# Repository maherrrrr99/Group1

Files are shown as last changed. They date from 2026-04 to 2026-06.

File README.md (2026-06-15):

# Pick-and-Place Robot Workflow

This project uses a laptop for YOLO detection, a Raspberry Pi as the camera and command bridge, and an Arduino for the arm, suction pump, and platform motors.

The suction pump is controlled through a relay on Arduino pin `D10`. The command names are unchanged: `SUCTION_CUP_ON` energizes the relay and `SUCTION_CUP_OFF` releases it.

## Expected Network Setup

- Raspberry Pi IP: `192.168.1.62`
- Pi camera stream: `http://192.168.1.62:8080/?action=stream`
- Pi receiver TCP port: `5000`
- Pi website command bridge: `http://192.168.1.62:5001`
- Laptop sender message format: `ball,x,y,distance`
- Arduino serial: `/dev/ttyACM0` or `/dev/ttyUSB0`, baud `9600`

## Start Camera Stream On Raspberry Pi

From the `mjpg_streamer` folder on the Raspberry Pi:

```bash
./mjpg_streamer -i "./input_uvc.so -d /dev/video0 -r 240x180 -f 7 -q 25" -o "./output_http.so -w ./www -p 8080"
```

Verify from the laptop:

```text
http://192.168.1.62:8080/?action=stream
```

## Start Raspberry Pi Receiver

Copy or keep `pi_receiver.py` on the Raspberry Pi, then run:

```bash
python3 -m pip install pyserial
python3 pi_receiver.py
```

The receiver listens on `0.0.0.0:5000` for laptop YOLO data and `0.0.0.0:5001` for website manual commands. It auto-detects `/dev/ttyACM0` or `/dev/ttyUSB0`, and sends `PLATFORM_STOP` whenever data is lost, the laptop disconnects, or the receiver starts.

Verify the website command bridge from the laptop:

```powershell
Invoke-WebRequest http://192.168.1.62:5001/status
```

Object tracking is enabled in `pi_receiver.py` with these safe defaults:

- Platform speed command on startup: `PLATFORM_BOTH_MOTORS_SPEED:SLOW`
- Centering dead zone: `20` pixels around frame center X `160`
- Target ball distance: `25 cm`
- Distance dead zone: `4 cm`
- Tracking command order: turn left/right first, then move forward/backward only after the ball is centered

To make tracking more cautious, increase `TARGET_DISTANCE_CM`, increase `DISTANCE_DEAD_ZONE_CM`, or set `AUTONOMOUS_TRACKING_ENABLED = False` in `pi_receiver.py`.

Calibrated physical home:

- Elbow command `55` = physical elbow `90` degrees
- Wrist command `0` = physical wrist `0` degrees
- Gripper command `90` = home gripper angle

Calibrated elbow endpoints for website control:

- Physical elbow `0` degrees sends Arduino command `10`
- Physical elbow `90` degrees sends Arduino command `55`
- Physical elbow `180` degrees sends Arduino command `115`

The website elbow slider shows physical degrees. It converts those physical degrees to the calibrated Arduino command before sending `ELBOW_JOINT:<angle>`.

Calibrated wrist endpoints for website control:

- Physical wrist `0` degrees sends Arduino command `0`
- Physical wrist `80` degrees sends Arduino command `110`

The wrist is capped at physical `80` degrees because Arduino command `110` is the measured safe maximum.

Arm pickup is guarded by `PICKUP_SEQUENCE_ENABLED = False` until calibration is complete. Use `arm_calibration.py` on the Raspberry Pi to find safe values first, then copy those values into:

- `PICKUP_TRIGGER_DISTANCE_CM`
- `PICKUP_ELBOW_ANGLE`
- `PICKUP_WRIST_ANGLE`
- `PICKUP_GRIPPER_ANGLE`
- `PICKUP_USE_SUCTION`

## Calibrate Arm Angles On Raspberry Pi

Stop autonomous tracking first so no platform commands are active:

```powershell
Get-Process python,py | Stop-Process -Force
```

Then on the Raspberry Pi:

```bash
pkill -f pi_receiver.py
python3 ~/arm_calibration.py
```

Calibration controls:

```text
e / E : elbow -5 / +5 degrees
w / W : wrist -5 / +5 degrees
g / G : gripper -5 / +5 degrees
s     : suction cup on
x     : suction cup off
h     : home
p     : platform stop
?     : print current values
q     : quit
```

Record the elbow, wrist, and gripper values that place the tool safely at the egg.

## Live Feed Delay

The website preview can lag because browser MJPEG display buffers frames. Use the laptop YOLO sender log and Pi receiver log for control timing. For less delay, keep the stream low resolution and refresh/restart `mjpg_streamer` if the browser preview falls behind.

## Run Laptop YOLO Sender

From this project folder on the laptop:

```bash
python -m pip install ultralytics opencv-python
python laptop_yolo_sender.py
```

The script uses:

```text
train27-20260608T072150Z-3-001/train27/weights/best.pt
```

It sends only the most confident `ball` detection every `0.3` seconds.

For autonomous object tracking, start the Raspberry Pi receiver first, then run this laptop sender. The receiver will stop the platform automatically if ball data stops for more than `1` second.

## Run Website

From the website folder:

```bash
cd "pick and place website/pick and place website/2026-05-19/i-am-working-on-a-mechatronics/arm-controller"
npm install
npm run dev
```

Open:

```text
http://localhost:5173
```

Use Chrome or Edge for Web Serial.

### HC-05 Bluetooth manual control

The Arduino sketch uses `SoftwareSerial bluetooth(2, 3)` at `9600` baud:

```text
HC-05 TXD -> Arduino D2  (Arduino software RX)
HC-05 RXD -> Arduino D3  (Arduino software TX, use a voltage divider)
HC-05 VCC -> Arduino 5V
HC-05 GND -> Arduino GND
```

Pair the HC-05 in Windows first, then open the website, choose `Bluetooth`, click connect, and select the HC-05/SPP COM port. The website sends the same command names used by USB serial, such as `HOME`, `PLATFORM_STOP`, `ELBOW_JOINT:<angle>`, and `SUCTION_CUP_ON`.

To control the Arduino through the Raspberry Pi instead of HC-05/USB, choose `Autonomous Network`; the website sends commands to `http://192.168.1.62:5001/command`.

Keep the existing Arduino command names, including `PLATFORM_LEFT`, `PLATFORM_RIGHT`, `PLATFORM_STOP`, `HOME`, `EMERGENCY_STOP`, `RESET_EMERGENCY`, `SUCTION_CUP_ON`, and `SUCTION_CUP_OFF`.

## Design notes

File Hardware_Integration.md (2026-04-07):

### ● Hardware Integration
The robotic system is built around a combination of a Raspberry Pi and an Arduino, which together enable both high-level processing and low-level control. The Raspberry Pi is responsible for vision processing, object detection, and decision-making using camera input, while the Arduino handles real-time control of the actuators by generating PWM signals for the motors. Communication between the two controllers is achieved through serial communication (USB or UART), allowing coordinated system operation.

The actuation system is based on multiple servo motors selected according to torque and functional requirements. MG995 servo motors (270° rotation) are used for standard joints, providing sufficient torque for base and intermediate movements. For heavier joints such as the elbow, a 20 kg·cm high-torque servo motor (270° rotation) is used to ensure stability and lifting capability. The gripper mechanism is controlled using an SG90 micro servo (180° rotation), which offers lightweight and precise motion for opening and closing actions. All motors are controlled using PWM signals from the Arduino, and no external encoders are required since the servos include built-in potentiometers, enabling closed-loop position control.
<div align="center">

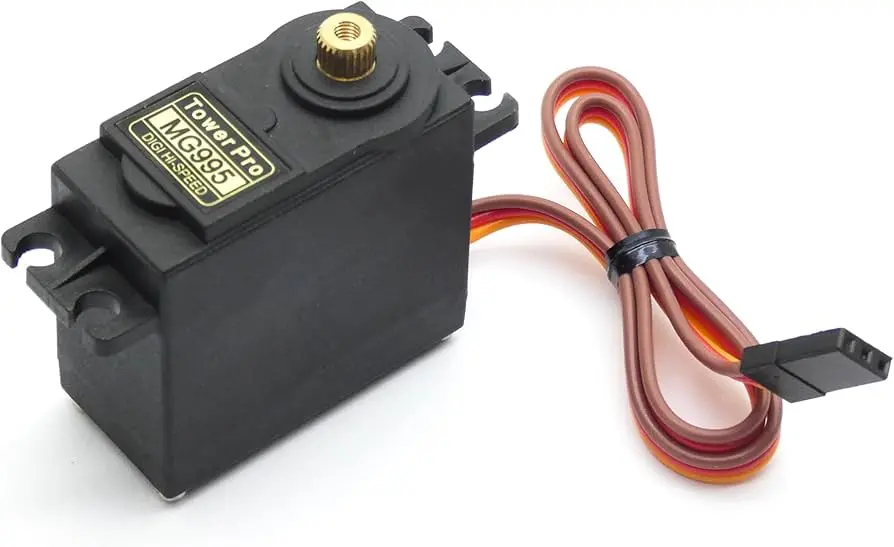
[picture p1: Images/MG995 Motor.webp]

&nbsp;&nbsp;&nbsp;&nbsp;&nbsp;&nbsp;
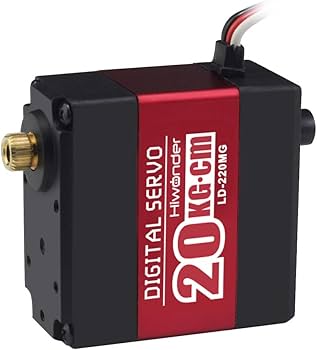
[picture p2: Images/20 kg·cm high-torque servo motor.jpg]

&nbsp;&nbsp;&nbsp;&nbsp;&nbsp;&nbsp;
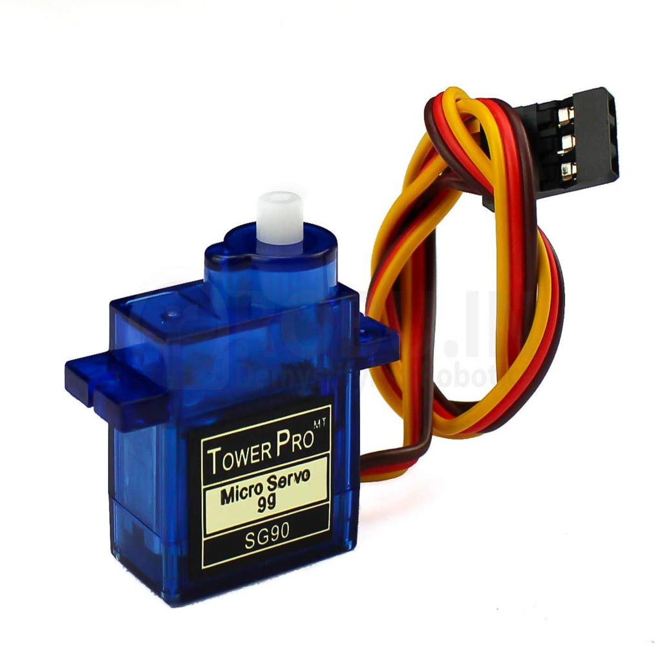
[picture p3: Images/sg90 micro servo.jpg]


<br>

<em>Figure 1: MG995 Servo Motor (left), 20 kg·cm High-Torque Servo (center), and SG90 Micro Servo (right)</em>

</div>

For sensing and object detection, the system integrates a camera connected to the Raspberry Pi. The current design considers either the Raspberry Pi Camera Module, which offers seamless integration and low latency, or a smartphone camera as an alternative for higher image quality. The camera provides real-time visual feedback, which is processed using computer vision and AI techniques to identify and locate objects for pick-and-place operations.
<p align="center">
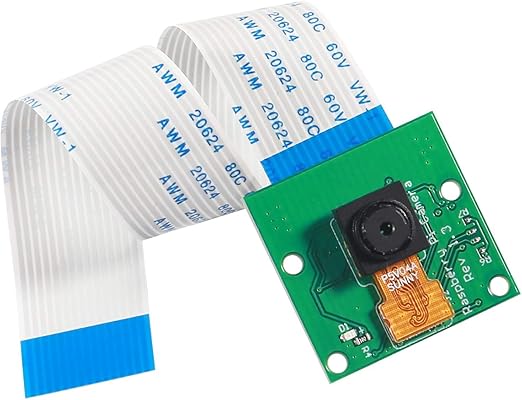
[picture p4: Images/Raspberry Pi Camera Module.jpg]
  
</p>
<p align="center"><em>Figure 2: Raspberry Pi Camera Module</em></p>

In terms of hardware layout and wiring, the servo motors are connected to the Arduino’s PWM pins and powered using an external power supply to ensure stable operation and prevent overloading the control board. The Raspberry Pi interfaces directly with the camera and communicates with the Arduino to send control commands based on processed visual data. This architecture allows efficient integration of mechanical, electronic, and intelligent subsystems, resulting in a flexible and scalable mechatronic system.

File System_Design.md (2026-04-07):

## ○ System Design

### ● Concept Development
The concept development process was iterative and systematic, building on existing literature and proven industrial designs rather than trying to reinvent the wheel. The goal was to adapt known pick-and-place mechanisms into a compact, efficient system that meets our specific needs. Throughout the design process, we focused on keeping the structure simple, durable, and practical, while also making sure it could be manufactured easily and affordably in a lab setting using tools like laser cutting and 3D printing. Another key consideration was compatibility with widely available, off-the-shelf components such as MG995 servo motors and Arduino-based control systems, which helped keep costs low and integration straightforward. Design decisions were guided by requirements like strength, reliability, and repeatability, while working within constraints such as limited resources and fabrication methods. The end result is a compact, robust design that can withstand repeated use without compromising performance.

### ● CAD Modeling
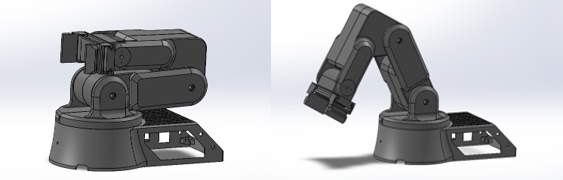
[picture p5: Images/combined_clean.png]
CAD Rendering


Figure 1: CAD Model in home and extended position.
- [CAD (SolidWorks) ](CAD_SolidWorks.zip)
- [STEP File](assembly.STEP)

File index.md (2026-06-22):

# Smart Pick-and-Place Robot
### MEC483 — Mechatronic System Design · Spring 2025–2026
#### College of Engineering · Instructor: Dr. Claudio Vignola

<p align="center">
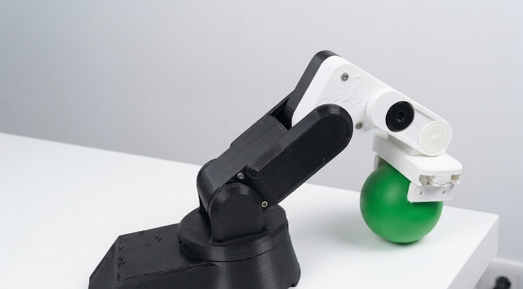
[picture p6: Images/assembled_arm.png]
  
</p>

---

## Team Members

- [Maher Abo Abed](https://maherrrrr99.github.io/maherrrrr99/)
- [Sabeeha Zainab Hasham](https://sabeehahasham.github.io/)
- [Basel Feras Ghunaim](https://basel-ghunaim.github.io/)
- [Ahmed Nasser Alshehhi](https://ahmed1090822.github.io/Ahmed109.github.io/)

---

## Problem Statement

Modern manufacturing and automation systems demand fast, accurate, and reliable object handling. Manual pick-and-place operations are slow, prone to human error, and unsuitable for repetitive, high-precision tasks. Traditional robotic systems are typically designed to work with objects in fixed locations and cannot adapt to changing environments.

To tackle these challenges, this project builds a **Smart Pick-and-Place Robotic System** with integrated computer vision. The system automatically identifies objects in a workspace, determines their positions, and commands a robotic arm to pick and place them — entirely without human intervention. It combines sensing, image processing, embedded control, and mechanical actuation into a smart, efficient automation solution.

### Impact

The system demonstrates the application of mechatronic engineering principles through the tight integration of mechanical, electrical, control, and computer engineering subsystems. By embedding computer vision directly into the robotic arm pipeline, the system improves detection precision and reduces reliance on manual handling. The platform also serves as a foundation for future developments in advanced object recognition and fully autonomous industrial robotics.

### Design Criteria

| # | Criterion | Goal |
|---|---|---|
| CR-1 | Object Detection Accuracy | Reliable identification of eggs, nuts, bolts, balls, and compasses |
| CR-2 | Pick-and-Place Success Rate | Consistent end-to-end cycle completion |
| CR-3 | Positioning Accuracy | Precise placement with minimal offset |
| CR-4 | Response Time | Low-latency vision-to-motion pipeline |
| CR-5 | Payload Capacity | Handle objects up to 250 g |
| CR-6 | Repeatability | Consistent performance across multiple cycles |
| CR-7 | Workspace Coverage | Full reach over the 30 cm platform footprint |

---

## The Robot

The final system is a **3-DOF robotic arm** mounted on a **differential-drive mobile platform**. The arm integrates a hybrid end-effector combining a rack-and-pinion mechanical gripper and a vacuum suction cup, enabling it to handle a wide variety of object shapes and textures. A Logitech C270 webcam feeds a live stream to a laptop running YOLOv8; detections are relayed over TCP to a Raspberry Pi 4 which sends joint commands to an Arduino Uno controlling the servo motors and suction pump.

<p align="center">
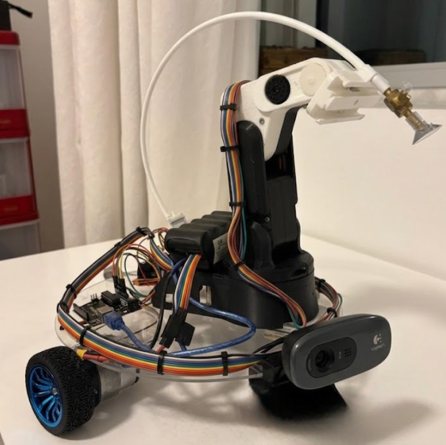
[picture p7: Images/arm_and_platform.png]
  
</p>
<p align="center"><em>Fig 1: Fully assembled arm mounted on the 30 cm acrylic laser-cut platform</em></p>

<p align="center">
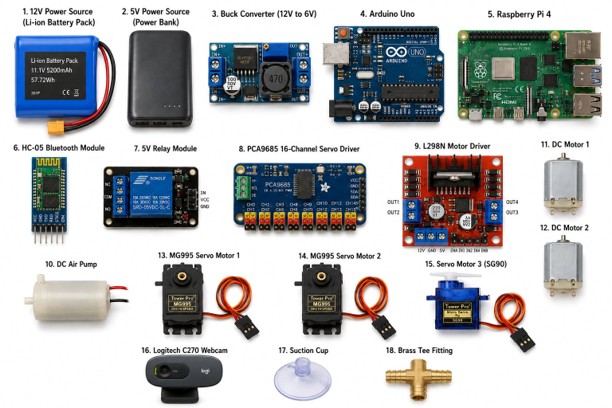
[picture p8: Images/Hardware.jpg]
  
</p>
<p align="center"><em>Fig 2: Complete hardware setup — electronics, arm, platform, and camera</em></p>

### Workspace Envelope

| Measurement | Value |
|---|---|
| Platform diameter (home footprint) | 30 cm |
| Extended arm reach beyond platform edge | ~16.5 cm |
| Maximum reach to lowest point (incl. suction cup) | **~22 cm** |
| Maximum horizontal reach (height unconstrained) | **~26 cm** |
| IK solver validated range — X | 0.05 – 0.20 m |
| IK solver validated range — Y | −0.10 – 0.10 m |
| IK solver validated range — Z | 0.02 – 0.07 m |

---

## CAD Design

The robot was modelled entirely in SolidWorks. All structural components — base, elbow, wrist, end-effector — were designed for 3D printing in PLA on a Raise3D E2 printer, with servo pockets and horn-mounting features printed accurately at each joint. The platform chassis was laser-cut from acrylic for flatness and rigidity, ensuring accurate motor alignment for differential drive.

<p align="center">
  
</p>
<p align="center"><em>Fig 3: CAD model — home position (left) and fully extended position (right)</em></p>

<p align="center">
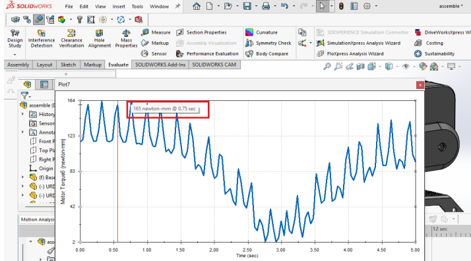
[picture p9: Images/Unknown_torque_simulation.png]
  
</p>
<p align="center"><em>Fig 4: SolidWorks Motion Study — torque simulation with 250 g payload confirms motor selection</em></p>

The torque simulation confirmed that the MG995 servos (rated ~11 kg·cm at 6 V) comfortably cover the worst-case joint loads when the arm is fully extended with a 250 g object, validating the actuator selection before any physical parts were built.

- [SolidWorks CAD Files](CAD_SolidWorks.zip)
- [STEP Assembly File](assembly.STEP)
- [STL Files for 3D Printing](STL.zip)

---

## Gripper Design

The end-effector uses a **rack-and-pinion mechanical gripper** combined with a **vacuum suction cup**, both 3D-printed in PLA. The pinion is attached directly to the output shaft of an SG90 servo, driving two symmetric linear racks that open and close the jaws. The suction cup is mounted coaxially on top of the gripper casing, connected to a 6 V DC air pump via a relay on Arduino pin D10 — allowing either gripping mode to be used independently based on the object type.

<p align="center">
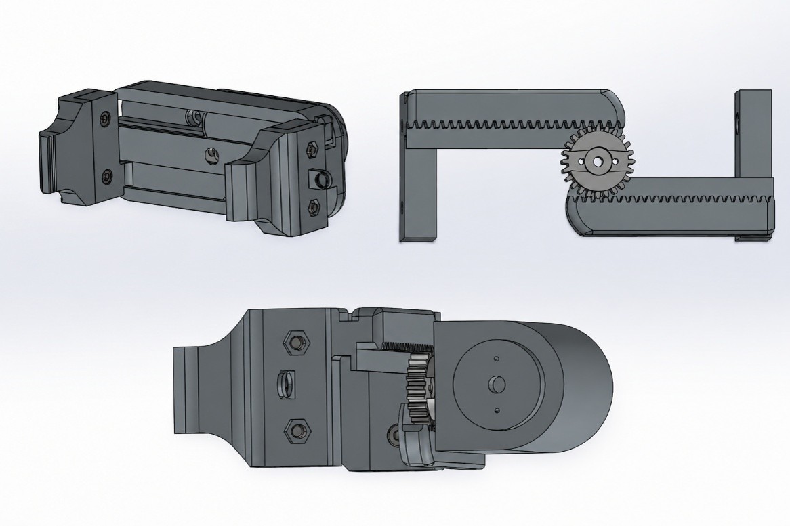
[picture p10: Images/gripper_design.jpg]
  
</p>
<p align="center"><em>Fig 5: 3D-printed hybrid gripper — rack-and-pinion jaws (bottom) and suction cup (top)</em></p>

| Mode | Best For | Control |
|---|---|---|
| Mechanical gripper | Nuts, bolts, rigid objects | SG90 servo via PCA9685 |
| Vacuum suction | Eggs, flat surfaces, smooth objects | DC pump via relay on Arduino D10 |

---

## Kinematics

### Forward Kinematics

The kinematic chain (`base_link → elbow_link → wrist_link → arm_link → end_link`) was modelled in URDF, exported from SolidWorks STL meshes. The URDF was validated in `robot_state_publisher` and visualised in RViz, confirming correct link orientation, joint hierarchy, and workspace geometry. Joint sliders were used to command each joint independently and verify that the forward kinematics matched the physical arm's motion.

<p align="center">
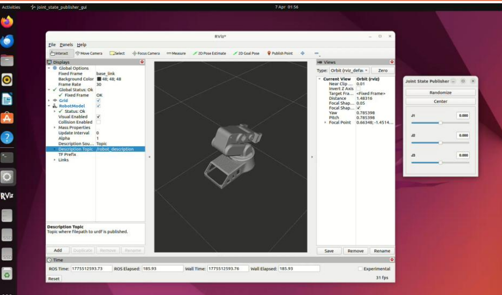
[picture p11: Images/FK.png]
  
</p>
<p align="center"><em>Fig 6: Forward kinematics visualisation in RViz — joint slider control</em></p>

### Inverse Kinematics

An IK pipeline was built with **ROS 2 Humble** and **MoveIt 2**, using the KDL solver configured for **position-only IK** (`position_only_ik: true`). This is appropriate for pick-and-place: the solver computes joint angles for a given (X, Y, Z) target without constraining end-effector orientation. A `workspace_scan.cpp` node swept a of 40 Cartesian test points and confirmed **100% reachability** across the full operating workspace.

<p align="center">
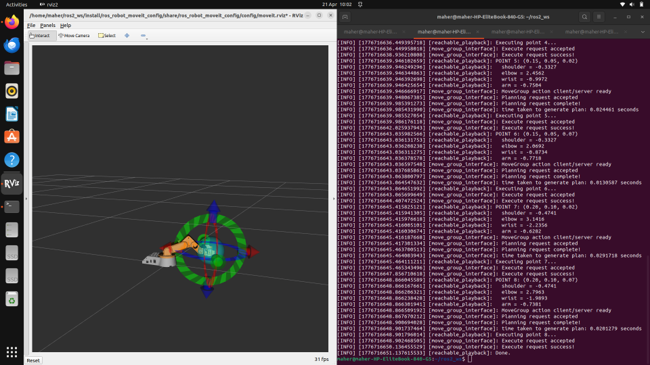
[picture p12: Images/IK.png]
  
</p>
<p align="center"><em>Fig 7: Inverse kinematics — workspace scan in RViz confirming 100% reachability over 40 test points</em></p>

#### Validated Reachable Points (sample)

| X (m) | Y (m) | Z (m) | Result |
|---|---|---|---|
| 0.05 | 0.00 | 0.02 | ✅ Reachable |
| 0.10 | 0.05 | 0.07 | ✅ Reachable |
| 0.20 | 0.10 | 0.07 | ✅ Reachable |
| 0.15 | −0.05 | 0.04 | ✅ Reachable |
| 0.08 | −0.10 | 0.05 | ✅ Reachable |

<p align="center">
  
</p>
<p align="center"><em>Fig 8: URDF robot simulation — motion planning in RViz</em></p>

### ROS Package

The full ROS 2 package is included in the [`ROS/`](ROS/) directory:

| File / Folder | Description |
|---|---|
| [`ROS/urdf/ros.urdf`](ROS/urdf/ros.urdf) | URDF kinematic model of the arm |
| [`ROS/meshes/`](ROS/meshes/) | STL meshes for each link (base, elbow, wrist, arm, end effector) |
| [`ROS/launch/display.launch`](ROS/launch/display.launch) | RViz visualisation launch file |
| [`ROS/launch/gazebo.launch`](ROS/launch/gazebo.launch) | Gazebo simulation launch file |
| [`ROS/config/joint_names_ros.yaml`](ROS/config/joint_names_ros.yaml) | Joint name configuration |
| [`ROS/package.xml`](ROS/package.xml) | ROS package manifest |
| [`ROS/CMakeLists.txt`](ROS/CMakeLists.txt) | Package build configuration |

```bash
# Visualise the arm in RViz
ros2 launch ros display.launch

# Run in Gazebo simulation
ros2 launch ros gazebo.launch
```

- [URDF Model File (legacy)](Files/urdf.urdf)

---

## Electrical System

The electrical architecture is split across three voltage rails to keep logic and power isolated:

- **12 V** — main Li-ion battery pack (12 V, 3000 mAh, 36 Wh)
- **6 V** — buck converter output for all actuators (servos, DC motors, air pump)
- **5 V** — regulated supply for Arduino, Raspberry Pi, Bluetooth module, and all signal lines

All grounds are tied to a single common bus to prevent electrical noise from high-current motor and servo wiring from interfering with signal lines.

<p align="center">
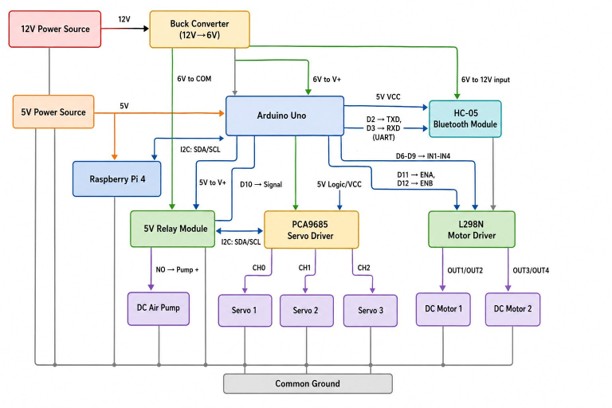
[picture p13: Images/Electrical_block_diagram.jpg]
  
</p>
<p align="center"><em>Fig 9: Final electrical block diagram</em></p>

<p align="center">
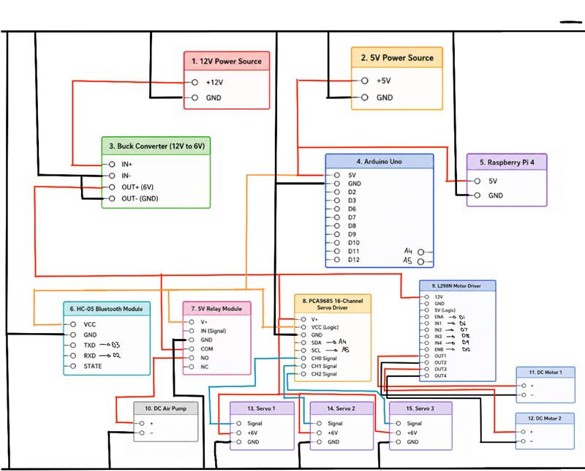
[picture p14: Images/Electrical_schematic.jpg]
  
</p>
<p align="center"><em>Fig 10: Electrical schematic — red: 12–6 V power, black: ground, blue: servo signals, orange: 5 V VCC</em></p>

### Power Budget Summary

| Subsystem | Voltage | Peak Current | Peak Power |
|---|---|---|---|
| MG995 Servo × 2 (Wrist + Elbow) | 6 V | 2.0 A each | 12.0 W each |
| SG90 Servo (Gripper) | 6 V | 650 mA | 3.9 W |
| DC Motor × 2 (Platform) | 6 V | 1.2 A each | 7.2 W each |
| DC Air Pump | 6 V | 400 mA | 2.4 W |
| Raspberry Pi 4 | 5 V | 1.2 A | 6.0 W |
| Arduino Uno | 5 V | 80 mA | 0.4 W |
| **6 V Rail Total (peak)** | 6 V | **7.45 A** | **44.7 W** |
| **Estimated runtime (normal use)** | — | — | **~4 hours** |

### Component Selection

All major components were chosen using weighted decision matrices (scored 1–5). Key results:

| Component | Selected | Score | Runner-up |
|---|---|---|---|
| Microcontroller | Arduino UNO | 4.20 | ESP32 (3.70) |
| Camera | Logitech C270 | 4.85 | InnoMaker USB (2.75) |
| Mini-computer | Raspberry Pi 4 | 4.60 | NVIDIA Jetson Nano (2.60) |
| Arm actuator | MG995 / SG90 Servo | 4.30 | DC Motor + Gearbox (2.80) |

<div align="center">
  
  &nbsp;&nbsp;&nbsp;
  
  &nbsp;&nbsp;&nbsp;
  
</div>
<p align="center"><em>Fig 11: MG995 (left) · 20 kg·cm High-Torque Servo (center) · SG90 Micro Servo (right)</em></p>

---

## Computer Vision

The vision pipeline combines **YOLOv8 deep learning** with **HSV colour filtering** for a hybrid detection system — accuracy of machine learning with the speed and simplicity of colour-based processing.

### Dataset & Annotation

Five object classes were targeted: **egg, nut, bolt, compass, and ball**. Egg images were sourced from the Open Images Dataset; compass images were captured manually; nut and bolt datasets were partially sourced from Roboflow and partially captured in-lab. All images were annotated in **CVAT** with bounding boxes, exported in YOLO 1.1 format, and split 80/20 into training and validation sets.

<p align="center">
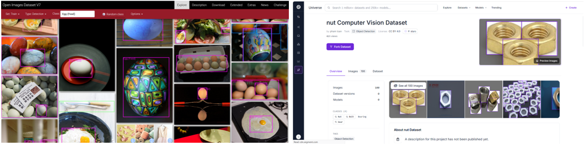
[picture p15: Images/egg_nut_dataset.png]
  
</p>
<p align="center"><em>Fig 12: Sample images from the custom egg and nut datasets</em></p>

<p align="center">
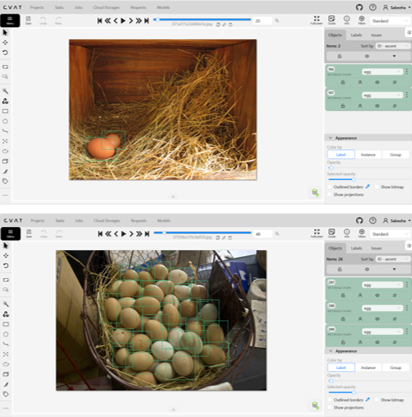
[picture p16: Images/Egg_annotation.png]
  
</p>
<p align="center"><em>Fig 13: CVAT bounding box annotations — each egg in the frame produces one row of YOLO coordinates</em></p>

### YOLOv8 Training

The model was trained for **100 epochs** in PyCharm using the Ultralytics YOLOv8 framework on the annotated custom dataset. Training monitored precision, recall, and mAP. The resulting `best.pt` weights were used for all subsequent testing and deployment.

<p align="center">
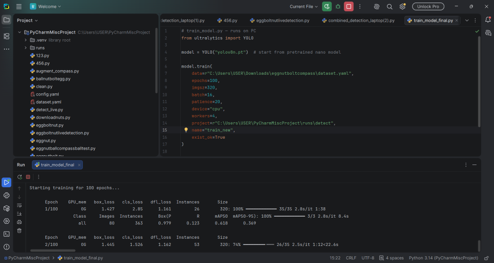
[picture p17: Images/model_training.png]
  
</p>
<p align="center"><em>Fig 14: YOLOv8 training curves — loss, precision, recall, and mAP over 100 epochs</em></p>

### HSV Colour Calibration

HSV filtering was implemented for green ball detection using OpenCV. The HSV colour space separates colour from brightness, making it robust to lighting variation. An interactive calibration tool with live trackbars was used to determine optimal threshold values.

<p align="center">
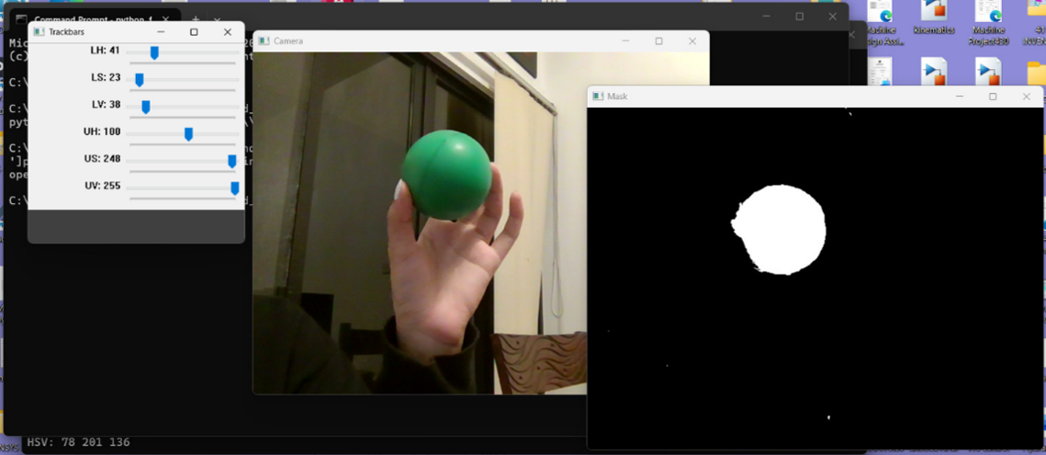
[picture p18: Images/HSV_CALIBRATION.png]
  
</p>
<p align="center"><em>Fig 15: HSV calibration tool — adjustable LH/LS/LV/UH/US/UV sliders with live binary mask preview</em></p>

### Deployment on Raspberry Pi

After desktop validation in PyCharm, the model and scripts were transferred to the Raspberry Pi 4. Required dependencies (Ultralytics, OpenCV, NumPy, PyYAML, libcamera) were installed on Ubuntu. The Logitech C270 webcam was integrated and resolution was tuned to balance detection accuracy against processing speed.

<p align="center">
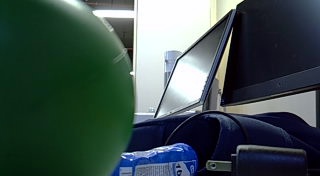
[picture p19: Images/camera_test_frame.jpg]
  
</p>
<p align="center"><em>Fig 16: Test frame from the live Raspberry Pi camera stream</em></p>

<p align="center">
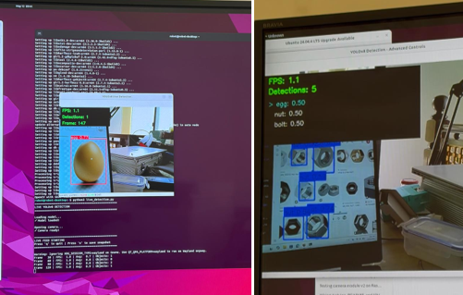
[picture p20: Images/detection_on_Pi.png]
  
</p>
<p align="center"><em>Fig 17: YOLOv8 running on Raspberry Pi — real-time multi-class detection with confidence scores</em></p>

---

## Distance Estimation

To determine when the robot is close enough to initiate a pickup, the vision system estimates object distance from the camera using each object's known physical size. Because no depth sensor is used, distance is inferred from how large the object appears in pixels — as the object grows larger in the frame, the robot is getting closer; as it shrinks, it is moving further away.

The focal calibration value is computed using a reference measurement at a known distance:

$$F = \frac{D_{\text{known}} \times W_{\text{pixel}}}{W_{\text{real}}}$$

Each object class uses an appropriate dimension: the ball uses its diameter, the compass uses its outer width, the nut uses its bounding box width, and the egg uses its major axis height. To handle momentary detection gaps, a memory-based tracker holds the last valid detection for a short number of frames, keeping the distance output stable. The on-screen label **STABLE** confirms the object has been consistently detected across several successive frames, making the displayed distance reliable.

<p align="center">
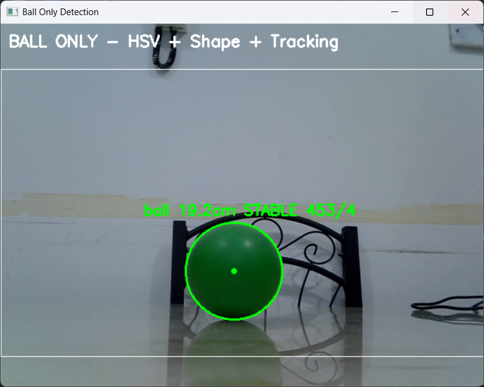
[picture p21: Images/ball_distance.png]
  
</p>
<p align="center"><em>Green ball detection with real-time distance estimation</em></p>

<p align="center">
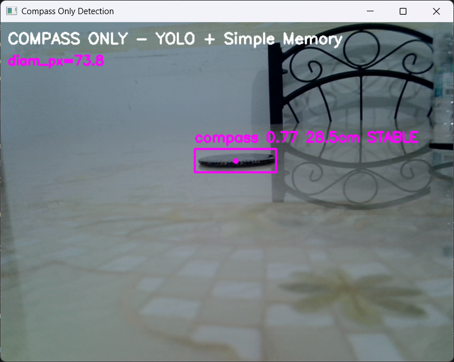
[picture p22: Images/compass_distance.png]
  
</p>
<p align="center"><em>Compass detection with real-time distance estimation</em></p>

> **Note:** Distance values are approximate unless calibrated against known reference distances for each object class and camera setup. Camera resolution, lens position, and experimental setup all affect the focal calibration value.

---

## Platform Autonomous Tracking

The Raspberry Pi receiver (`pi_receiver.py`) implements **autonomous object tracking** using the YOLOv8 position data from the laptop. When tracking is active, the platform steers left or right to centre the detected object in the camera frame, then moves forward or backward to reach the target distance. The shoulder joint is effectively replaced by the platform's differential-drive yaw — a deliberate design simplification that reduced the arm from 4-DOF to 3-DOF while preserving full workspace coverage.

<p align="center">
  
</p>
<p align="center"><em>Fig 18: Live demonstration — platform autonomously tracking and centring on a detected object</em></p>

**Tracking parameters (safe defaults):**

| Parameter | Value |
|---|---|
| Platform speed | `PLATFORM_BOTH_MOTORS_SPEED:SLOW` |
| Centering dead zone | ±20 px around frame centre (X = 160) |
| Target approach distance | 25 cm |
| Distance dead zone | ±4 cm |
| Tracking command order | Turn to centre → then advance/retreat |
| Data loss timeout | Platform stops after 1 s without detection |

---

## Interactive Website

A full web control interface was built using **Vite + Web Serial API**, providing both manual and autonomous control modes. The site connects to the robot over USB serial, Bluetooth (HC-05), or through the Raspberry Pi network bridge (`http://192.168.1.62:5001`).

<p align="center">
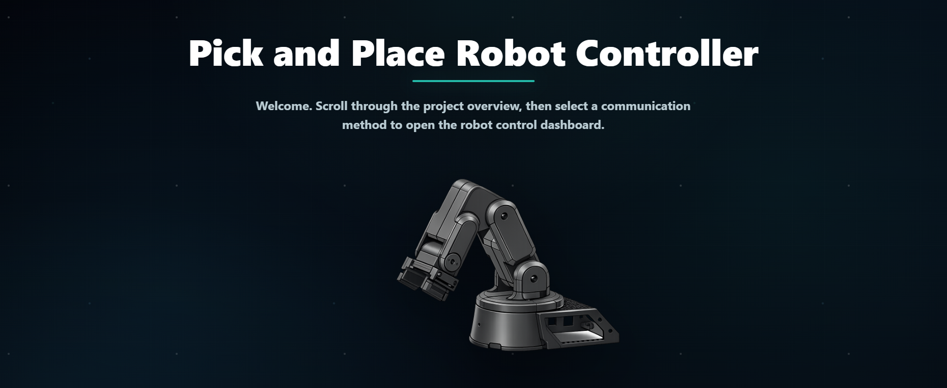
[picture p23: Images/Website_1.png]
  
</p>
<p align="center"><em>Fig 19: Main control panel</em></p>

<p align="center">
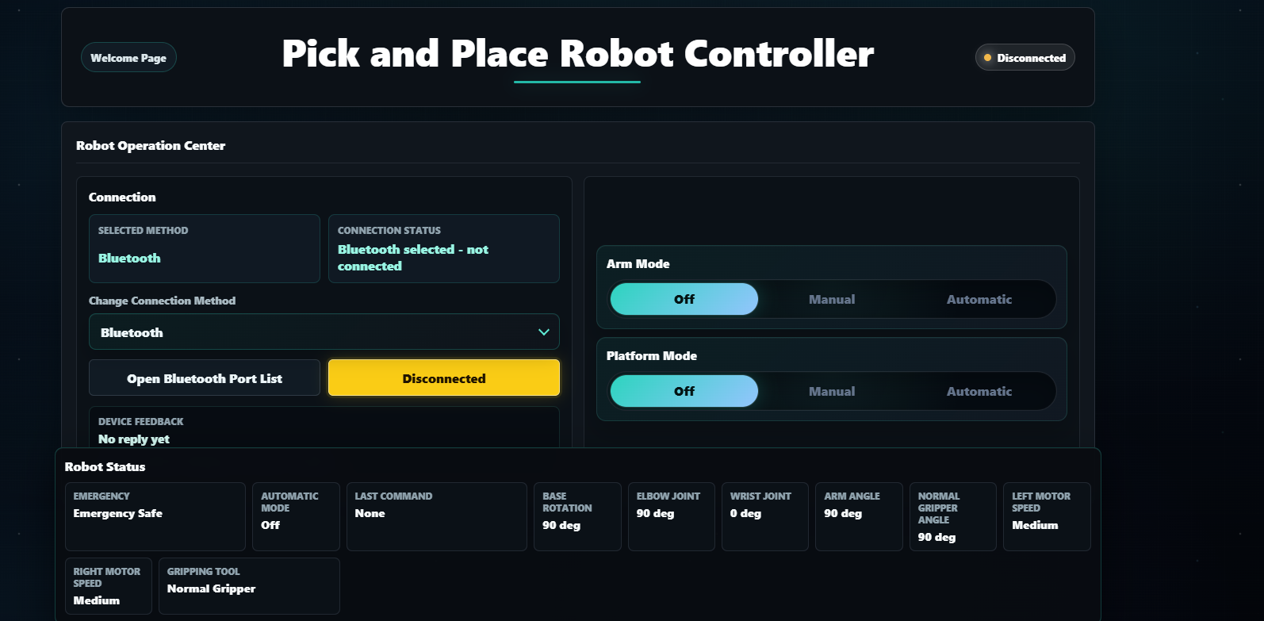
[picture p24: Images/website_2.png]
  
</p>
<p align="center"><em>Fig 20: Joint sliders with calibrated physical-degree-to-PWM conversion</em></p>

<p align="center">
  
</p>
<p align="center"><em>Fig 21: Platform directional controls and live camera feed</em></p>

<p align="center">
  
</p>
<p align="center"><em>Fig 22: Connection settings — USB Serial, Bluetooth, or Autonomous Network mode</em></p>

**Key features:**
- Elbow and wrist sliders show **physical degrees** and convert to calibrated PWM ticks before sending
- Platform controls: forward, backward, left, right, stop, speed preset
- Suction cup ON / OFF toggle
- Home position and emergency stop
- Autonomous tracking toggle (delegates full control to `pi_receiver.py`)
- Live MJPEG camera feed embedded

```bash
# Run the website locally
cd "Website/arm-controller"
npm install
npm run dev
# Open http://localhost:5173 in Chrome or Edge (required for Web Serial)
```

---

## Autonomous Mode Testing

With all subsystems fully integrated — YOLOv8 detection on the laptop, TCP communication to the Raspberry Pi, platform tracking, and Arduino joint control — the complete autonomous pipeline was tested end-to-end. The robot successfully detected target objects, steered the platform to centre and approach them, and executed the pick-and-place sequence without any manual input. All systems performed as expected and the results were successful.

<p align="center">
  
</p>
<p align="center"><em>Full autonomous mode test — object detection, platform tracking, arm movement, and pick sequence running without human intervention</em></p>

---

## System Testing

<p align="center">
  
</p>
<p align="center"><em>Fig 23: Full system integration test — detection, tracking, arm movement, and pick sequence</em></p>

Testing was conducted at both subsystem and full-system level:

| Test | Method | Outcome |
|---|---|---|
| Individual servo & joint calibration | Serial command interface, PWM sweep | All joints calibrated; elbow 150–600 ticks, wrist 570–1200 ticks |
| Motor & encoder verification | Differential drive test on flat surface | Straight-line motion and turning confirmed |
| YOLOv8 detection accuracy | Live camera, multiple objects, varied lighting | Reliable multi-class detection; confidence threshold tuned |
| HSV colour detection | Interactive trackbar calibration | Green ball isolated across viewing angles and lighting |
| IK workspace scan | 40-point Cartesian grid, MoveIt 2 | 100% reachability (40/40 points) |
| Wireless control link | HC-05 Bluetooth + website | Commands received and executed reliably |
| Platform autonomous tracking | Live object detection loop | Platform centres and approaches target |
| Full pick-and-place cycle | End-to-end run with egg and nut | Object detected → platform tracks → arm picks → places |

---

## Results

### Key Results Summary

| Component | Status | Outcome |
|---|---|---|
| CAD Design | ✅ Completed | Full SolidWorks model; torque validated at 250 g payload |
| 3D Printing & Fabrication | ✅ Completed | All arm links, joints, and gripper printed in PLA |
| Electrical Integration | ✅ Completed | 3-rail power system; common ground; all components wired |
| Arduino Firmware | ✅ Completed | Joint control, relay, motor driver, serial command interface |
| Computer Vision (HSV) | ✅ Completed | Green ball detection with interactive calibration |
| Computer Vision (YOLOv8) | ✅ Completed | 100-epoch custom model; deployed on Raspberry Pi |
| ROS 2 Forward Kinematics | ✅ Completed | URDF validated in RViz; all joints move correctly |
| ROS 2 Inverse Kinematics | ✅ Completed | MoveIt 2 KDL solver; 100% reachability over test grid |
| Interactive Website | ✅ Completed | Full manual and autonomous control via Web Serial |
| Platform Autonomous Tracking | ✅ Completed | Real-time object following with dead-zone control |
| Full Pick-and-Place Pipeline | ✅ Completed | End-to-end autonomous operation demonstrated |

---

## Discussion

The system was successfully integrated and demonstrated end-to-end autonomous operation. The key architectural decisions — offloading YOLOv8 inference to the laptop, using the Raspberry Pi as a command bridge, and replacing the shoulder joint with platform yaw steering — all proved effective in practice, reducing cost and complexity without limiting capability.

The hybrid gripper design handled both rigid (nuts, bolts) and delicate (eggs) objects without hardware reconfiguration. The dual-mode vision pipeline (YOLOv8 + HSV) provided redundancy: HSV detection is faster and works without the TCP link, while YOLOv8 delivers more robust multi-class identification.

The IK workspace validation confirmed 100% solver reachability across the operating envelope, closing the loop from a Cartesian vision output to PWM joint commands on the physical arm.

### Version 2.0 — Lessons Learned

If this project were repeated, the following improvements would be made based on direct experience:

**1. Maintain Backup Options for Critical Components**
Evaluate alternative components before final procurement. The initial camera had to be replaced after testing revealed driver incompatibilities — identifying a compatible backup in advance would have saved significant development time.

**2. Ensure Mechanical Alignment and Precision**
Misalignment in joints directly impacts placement accuracy. Careful tolerance control during 3D printing and assembly reduces the need for repeated reprints and iterative calibration.

**3. Allocate Sufficient Time for System Integration**
Hardware–software integration consistently takes longer than expected due to compatibility issues. Reserving dedicated integration and troubleshooting time at the end of the project is essential.

**4. Improve Cable Management**
Mechanical stress on wires during arm movement led to intermittent faults. Strain relief mechanisms should be designed in from the start to improve reliability and reduce rework.

**5. Test in Realistic Conditions Early**
Individual subsystem tests did not catch all issues that appeared during full system integration. HSV colour thresholds in particular must be calibrated in the actual operating environment, not on a test bench. Repeated pick-and-place cycles are needed to surface performance issues.

**6. Prototype Critical Features Early**
The gripper mechanism caused integration difficulties that would have been identified sooner with earlier prototyping. Key subsystems should be validated for full-system fit before other resources are committed.

**7. Maintain Detailed Documentation Throughout**
Recording design decisions, wiring diagrams, and code changes throughout development significantly simplifies troubleshooting and knowledge transfer. Gaps in documentation slowed debugging when problems arose late in integration.

**8. Invest in Higher-Quality Materials and Components**
Higher-quality components improve durability, precision, and reliability. Investing in better materials reduces long-term maintenance, prevents premature failure, and avoids costly late-stage redesigns.

---

## Project Management

The project was organized across four subsystem streams — mechanical, electrical, software, and system integration — with weekly progress reviews and clear ownership per member.

## Gantt Chart

<p align="center">
  
</p>
<p align="center"><em>Initial project plan — task timeline and milestone schedule across the semester</em></p>

[View the live updated Gantt Chart](https://studentsaduac-my.sharepoint.com/:x:/g/personal/1087993_students_adu_ac_ae/IQDgdSjexyc-QrslRSKR7R1VAezfRiBIHZJzDOwBOP83DMI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)

---

## Code & Software

| Resource | Description |
|---|---|
| [Computer Vision Scripts](Computer_Vision/) | `laptop_yolo_sender.py`, `pi_receiver.py`, `arm_calibration.py` |
| [Arduino Sketch](Arduino/2_motors_arduino_noross.ino) | Joint control, motor driver, relay, serial interface |
| [Interactive Website](Website/arm-controller/) | Vite web app — manual and autonomous robot control |
| [YOLO Training Results](Computer_Vision/Training_Results/train27/) | `best.pt` weights, loss curves, confusion matrix |
| [Dataset Labels](Dataset/labels/) | YOLO 1.1 format bounding box annotations |

---

## Appendix

### Final Report

[📄 Final Report — Group 1 (PDF)](Files/Final_Report_Group1.pdf)

### Progress Reports

| Week | Format |
|---|---|
| [Week 2](Files/Progress-W2.pdf) | PDF |
| [Week 3](Files/Progress-W3.pdf) | PDF |
| [Week 4](Files/Progress-W4.pdf) | PDF |
| [Week 5](Files/Progress-W5.pdf) | PDF · [Slides](Files/Progress-W5.pptx) |
| [Week 6](Files/Progress-W6.pdf) | PDF · [Slides](Files/Progress-W6.pptx) |
| [Week 7](Files/Progress-W7.pptx) | Slides |
| [Week 8](Files/Progress-W8.pptx) | Slides |
| [Week 10](Files/Progress-W10.pdf) | PDF |
| [Week 11](Files/Progress-W11.pptx) | Slides |
| [Week 12](Files/Progress-W12.pptx) | Slides |

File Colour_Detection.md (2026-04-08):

HSV and colour detection.
This technique was used for objects like the ball because colour-based detection allows for fast and efficient classification, especially in real-time systems. By working in the HSV (Hue, Saturation, Value) colour space instead of the traditional RGB format, it becomes significantly easier to isolate specific colours under varying lighting conditions, as HSV separates colour information (hue) from brightness (value). In the project, the live camera feed was captured and converted into HSV format using OpenCV. Once in this format, a specific colour range was defined by selecting appropriate upper and lower HSV threshold values. These thresholds were used to generate a binary mask, where only the pixels that fell within the desired colour range were highlighted, while all other pixels were ignored. This masking process effectively filtered out background noise and irrelevant objects, allowing the system to focus only on the target object. The resulting mask was then processed further to detect contours or shapes, enabling the system to locate, track, and follow the object in real time. This approach improves both accuracy and computational efficiency, making it highly suitable for applications such as object tracking, pick-and-place robotics, and automated sorting systems.

This result also demonstrates the selectivity of the HSV masking process. The particular shade of green shown in the image was not detected by the system, as it fell outside the defined HSV threshold range. This indicates that the colour filtering was effectively tuned to isolate only the intended target colour, while successfully rejecting similar but unwanted shades. As a result, the system reduces false positives and improves overall detection accuracy.

This approach was also explored as a subsidiary method to refine the colour detection process. Instead of relying on a single fixed value, a broader HSV range was initially used to capture the target object. However, as shown in the image, this range proved to be too wide and not sufficiently specific, resulting in the detection of unwanted areas and noise within the frame. Similar colours and background elements were incorrectly included in the mask, reducing the precision of the system. This highlighted the importance of carefully tuning the HSV thresholds, as overly broad ranges can compromise accuracy, while more narrowly defined values improve selectivity and reliability in object detection.


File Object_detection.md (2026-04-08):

Training a yolov8 model
The classification process involved training a custom object detection model using YOLOv8 within PyCharm. First, image data for the objects was collected, labeled, and organized into training folders with corresponding annotation files. A configuration file (config.yaml) was created to define the dataset paths and class names. The model was then trained over multiple epochs, where it repeatedly processed the images, compared its predictions to the actual labels, and adjusted its internal parameters to improve accuracy. Performance metrics such as precision and recall were used to evaluate how well the model was learning. Finally, the trained model was tested using a live camera feed, where each frame was processed in real time, detections were made based on confidence thresholds, and bounding boxes with labels were displayed on the screen.

This image illustrates the annotation process carried out using CVAT, where a nut has been manually labelled with a bounding box. The bounding box is carefully drawn to tightly enclose the nut, ensuring that only the relevant object is captured while minimizing background noise. This precision is important because it helps the model learn the exact shape, size, and visual features of the nut. Each annotated object is assigned a class label, in this case nut, which is converted into a numerical class ID during training so the model can differentiate between multiple object types, such as eggs, nuts and bolts. By repeating this process across many images with varying positions, scales, and lighting conditions, a high-quality labelled dataset is created. This structured data is then used to train the YOLOv8 model, enabling it to accurately detect and classify nuts in new, unseen images or live camera input.


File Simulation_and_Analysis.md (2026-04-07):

## ○ Simulation and Analysis

### ● Mechanical
A mechanical analysis was performed in SolidWorks Motion Study to estimate the required torque at each joint throughout the robot’s movement. The simulation incorporated gravity effects and defined motor-driven joints to replicate realistic operating conditions. A predefined motion profile was applied to guide the arm through a representative pick-and-place cycle, allowing the software to compute the dynamic loads and torque demands over time. The results show peak torque values of approximately 165 N·mm at critical points in the motion. These values fall within the operating capabilities of the selected MG995 servo motors, confirming that the motor selection is appropriate for the intended application. Overall, the analysis validates that the system can operate reliably without overloading the actuators.
Simulation Results

### ● Kinematics (FK and IK)
Forward kinematics (FK) was implemented and visualized in RViz using ROS 2 to model the robot’s motion and verify link transformations. By defining the robot’s geometry and joint relationships, the end-effector position could be determined for given joint angles, allowing us to confirm that the arm reaches the desired workspace and behaves as expected. This also helped with debugging the overall structure and ensuring consistency between the CAD model and the software representation. In addition to FK, inverse kinematics (IK) will be implemented to enable the robot to compute the required joint angles for a desired end-effector position. This will allow for more intuitive control of the system, particularly for pick-and-place tasks where target positions are defined in Cartesian space.
Robot Demo
[URDF file used for the analysis](Files/urdf.urdf)

### ● Future Plans
Looking ahead, this project can be extended beyond a stationary setup into a mobile pick-and-place robot using ROS 2 and other open-source tools. Instead of being fixed in one place, the robot would be able to move around and carry out tasks in different locations. This would involve combining the current robotic arm with a mobile base and using simulation platforms like Gazebo to test everything in a safe, virtual environment before real-world implementation. To make the system more autonomous, SLAM can be used to help the robot map and understand its surroundings, while Nav2 can handle navigation tasks such as path planning and obstacle avoidance. This approach builds naturally on the current design and moves toward a more practical and intelligent robotic system using well-established, accessible technologies

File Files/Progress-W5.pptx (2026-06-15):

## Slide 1


WEEKLY PROGRESS REPORT

Mechatronic System Design (MEC483) – Course Project

Maher Abo Abed (1087993) , Sabeeha Zainab Hasham (1089042), Basel Feras Ghunaim (1088912), Ahmad Nasser Alshehhi (1090882)

PROJECT / PHASE

Smart Pick and Place Robot

31/4/2026 – 7/4/2026

DATE RANGE

TEAM MEMBERS

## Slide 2


HOW ARE WE DOING THIS WEEK?

TOP WINS

- Design: Finalized the CAD model, used OpenSCAD to parametrically design spur gears, conducted an unknown torque analysis in SolidWorks to verify motor selection, and started the printing process.
- Began the procurement process.
- Begin and are exploring the use open-source frameworks. Started with Rviz and Moveit2 to conduct FK and IK, by creating a URDF model and importing it to Ubuntu and ROS 2.
- Collected, cleaned and labeled egg image data, then trained a YOLOv8 model and tested it in real time using OpenCV to detect eggs.

KEY BLOCKERS / RISKS

- Blocker : Limited university access, making gathering as a group extremely difficult.
- Risk: The components are pricey, so every step has to be studied carefully before executing.
- Blocker: Uncertainty around the future of the semester is creating hesitation and doubt.
- Blocker: The run time of training datasets is massive, sometimes can take up to a day depending on the number of images used to train

PROJECT HEALTH

Scope

Under Execution

Schedule

Potential Delays

Fabrication & Prototyping

Under Execution

OPEN ISSUES

3 Active

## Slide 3

Project Schedule (Gantt)

Agile Gantt chart1.xlsx (https://studentsaduac-my.sharepoint.com/:x:/g/personal/1087993_students_adu_ac_ae/IQCVl5X-gnVOTbJbda9AOzVBAQxvkQVJ4Exoq-0edEJwLJE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)

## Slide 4


ISSUES, RISKS, AND ACTION ITEMS

- Due to current circumstances, teammates cannot meet in person to discuss project planning, this has resulted in Microsoft Teams meetings occurring 1-2 times a week. This can be limiting as only one teammate has access to the objects that need to be picked up by the arm.
- No access to university is slowing down work efforts, and overall progress.

MITIGATIONS / DECISIONS NEEDED

- Conduct virtual meetings often.
- Constant communication and updates.
- Each member should take their own initiatives.
- Aim to make any sort of progress, regardless of how small or big.

TOP ISSUES (BLOCKING PROGRESS)

ACTION ITEMS (NEXT 7 DAYS)

ID

A1

ACTION ITEM DESCRIPTION

Investigate how to mitigate issues experienced using vision detection

MEMBER

Sabeeha

WEEK DUE

Week 6

A2

A3

Finish the FK and IK kinematics

Maher

Basel

Week 6

Week 6

A4

Finalize gripper design + Pneumatic Integration

Finalize gripper design + Pneumatic Integration

Ahmad

Week 6

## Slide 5


INDIVIDUAL UPDATES

WEEKLY PROGRESS & NEXT STEPS

MEMBER 1

Maher Abo Abed

MEMBER 2

Sabeeha Zainab Hasham

MEMBER 3

Basel Feras Ghunaim

MEMBER 4

Ahmad Nasser Alshehhi

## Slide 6

ACCOMPLISHED (SINCE LAST REPORT)

- Finalized the CAD model.
- Parametrically designed spur gears using OpenSCAD.
- Conducted unknown torque analysis using SolidWorks to verify motor selection.
- Prepared STL files.
- Acquired few components.
- Preparing to use ROS 2 open-source frameworks.
- Created a URDF code
- Imported the code to Rviz and Moveit2, to conduct FK and IK.

IN PROGRESS

- Conducting the FK and IK
- Printing
- Further procurement

NEXT WEEK PLAN

- Mechanical assembly
- Finish the FK and IK
- Control the motors, by linking them to the classifier model.

MEMBER 1: Maher Abo Abed

EVIDENCE


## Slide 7


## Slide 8

ACCOMPLISHED (SINCE LAST REPORT)

Found a series of datasets for the egg, nut and bolt, downloaded, filtered the dataset to only to use appropriate images (from 800 images to 450), then annotated the dataset for the egg – this meant the corresponding annotations were downloaded in the YOLO format label file from cvat.
Installed PyCharm to train the Yolov8 model using the ultralytics library and tested it – used 450 images to train for the egg, dataset was clean and split into image files and their corresponding label txt files.
Training for 100 epochs showed higher accuracy using the live feed using openCV.

IN PROGRESS

To use the datasets for the other objects that I have and merge it with the egg one so it can identify multiple objects that we are using – test and ensure the accuracy is high.

NEXT WEEK PLAN

MEMBER 2: Sabeeha Hasham

EVIDENCE (SHOW, DON'T TELL)

•


•

•

•


•


Object detection refining – ensure it works for the other objects that we have using the data sets collected

•

HELP NEEDED / QUESTIONS

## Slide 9

MEMBER 3: Basel Feras Ghunaim

ACCOMPLISHED (SINCE LAST REPORT)

•

IN PROGRESS

- Implementing initial stepper motor control logic and testing basic motion behavior.
- Evaluating potential positioning errors due to gear backlash and belt elasticity.
- Optimizing suction cup placement and integration within the gripper design.
- Reviewing control sequence timing for coordinated pick-and-place operations.

- Completed evaluation of motion control strategies (AccelStepper vs custom step generation).
- Finalized decision to use stepper motor step-counting with homing as the primary positioning method.
- Conducted detailed analysis of encoder integration options (single encoder, dual encoder, and comparison with motor step tracking).
- Refined hybrid end-effector concept (mechanical gripper + suction cup) and validated feasibility for all target objects.
- Investigated vacuum pump specifications and confirmed suitability of electric vacuum pump over compressed air systems.


NEXT WEEK PLAN

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
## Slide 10

MEMBER 4: Ahmed Alshehhi

ACCOMPLISHED (SINCE LAST REPORT)

Reviewed research papers and technical resources on robotic gripper design.

•

IN PROGRESS

• Selecting the most suitable gripper design based on object shape, weight, and fragility
• Studying methods to control gripping force to ensure safe handling of delicate objects (e.g., egg)

•

Analyzed different gripper types (mechanical, soft grippers, and vacuum-based systems).

NEXT WEEK PLAN

HELP NEEDED / QUESTIONS

•

•

Finalize the gripper design and add it to the CAD model

Begin testing basic gripping concepts using a simple prototype

•

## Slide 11

WRAP-UP: WHAT WE NEED FROM THE INSTRUCTOR / STAKEHOLDERS

DECISIONS REQUESTED

ACTION ITEMS FOLLOW-UP

- Gripper design
- Pneumatic integration
- Exploring other required features such as a mobile robot and how this can be integrated
- Building on the computer vision model.

- Gripper design
- Pneumatic integration
- Exploring other required features such as a mobile robot and how this can be integrated

QUESTIONS / FEEDBACK

- Could you guide us on inserts and threading's for 3D parts. Is it necessary, if so, what is the best approach?

- https://maherrrrr99.github.io/maherrrrr99/
- https://sabeehahasham.github.io/
- https://basel-ghunaim.github.io/
- https://ahmed1090822.github.io/Ahmed109.github.io/

APPENDIX

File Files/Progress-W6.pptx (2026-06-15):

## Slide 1


WEEKLY PROGRESS REPORT

Mechatronic System Design (MEC483) – Course Project

Maher Abo Abed (1087993) , Sabeeha Zainab Hasham (1089042), Basel Feras Ghunaim (1088912), Ahmad Nasser Alshehhi (1090882)

PROJECT / PHASE

Smart Pick and Place Robot

7/4/2026 – 14/4/2026

DATE RANGE

TEAM MEMBERS

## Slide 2


HOW ARE WE DOING THIS WEEK?

TOP WINS

- Completed the gripper design (electrical + pneumatic)
- Completed forward kinematics
- Attempted three different approaches for inverse kinematics
- Established control of the motors through an interactive UI, considering it a method amongst alternatives of manual override
- Finalised the vision detection system – has fairly decent accuracy but can be used for initial testing until it is refined more

KEY BLOCKERS / RISKS

- Blocker :Completed 3D Parts were misplaced in the university, printing must be restarted .
- Blocker: Printing issues with the spur gears, alternative fabrication method needs to be considered (laser cutting)
- Blocker: The run time of training datasets is massive, sometimes can take up to a day depending on the number of images used to train

PROJECT HEALTH

Scope

Under Execution

Schedule

Potential Delays

Fabrication & Prototyping

Under Execution

OPEN ISSUES

3 Active

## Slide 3

Project Schedule (Gantt)

Agile Gantt chart1.xlsx (https://studentsaduac-my.sharepoint.com/:x:/g/personal/1087993_students_adu_ac_ae/IQCVl5X-gnVOTbJbda9AOzVBAQxvkQVJ4Exoq-0edEJwLJE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)


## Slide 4


ISSUES, RISKS, AND ACTION ITEMS

TOP ISSUES (BLOCKING PROGRESS)

- Fabrication delays
- No access to university is slowing down work efforts, and overall progress.

ACTION ITEMS (NEXT 7 DAYS)

ID

A1

ACTION ITEM DESCRIPTION

Finalize and deploy the computer vision model

MEMBER

Sabeeha

WEEK DUE

Week 7

A2

A3

Finish the IK kinematics

Maher

Basel

Week 7

Week 7

MITIGATIONS / DECISIONS NEEDED

- Conduct virtual meetings often.
- Constant communication and updates.
- Each member should take their own initiatives.
- Aim to make any sort of progress, regardless of how small or big.

A4

Procure, assemble, and experiment on gripper.

Finalize a manual override system

Ahmad

Week 7

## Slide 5


INDIVIDUAL UPDATES

WEEKLY PROGRESS & NEXT STEPS

MEMBER 1

Maher Abo Abed

MEMBER 2

Sabeeha Zainab Hasham

MEMBER 3

Basel Feras Ghunaim

MEMBER 4

Ahmad Nasser Alshehhi

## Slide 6

MEMBER 1: Maher Abo Abed

ACCOMPLISHED (SINCE LAST REPORT)

EVIDENCE

- Position based control of the motor
- Software developed to control angular position of motors using interactive GUI through a python code
- Attempted three approaches for inverse kinematics
- IKFast an analytical IK solver in ROS – Converts URDF to DAE, extracts kinematic chains, solves symbolic equations and gives a .cpp file – solver validation and IK were inconsistent – issue with modeling and kinematic chain
- Moveit2 – FK kinematics works fine – however IK Solver is 6 DOF, our system is 4 DOF is over constrained
- Manual ai-aided calculations using matlab

IN PROGRESS

- Inverse kinematic and assembly


NEXT WEEK PLAN

- Mechanical assembly
- Finish the IK
- Control the motors, by linking them to the classifier model.

- What is the best inverse kinematic approach, or what are possible solutions to my problems?

HELP NEEDED / QUESTIONS

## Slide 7


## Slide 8


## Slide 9

ACCOMPLISHED (SINCE LAST REPORT)

Made the dataset for the compass, and for half of the bolt identification (the rest was an online dataset) and annotated the objects - this meant the corresponding annotations were downloaded in the YOLO format label file from cvat.
Used PyCharm to train the Yolov8 model using the ultralytics library and tested it – used 400 images to train for the egg, nut, bolt and compass, the dataset was clean and split into image files and their corresponding label txt files – took 100 images for the dataset for the compass
Training for 100 epochs showed higher accuracy using the live feed using openCV for all of the objects – Connected the iVCam from my iPhone to my laptop to have my phone camera displayed as opposed to using the laptop camera – see if this increases accuracy.
Not holding up the objects to the camera also increase the sensitivity for detection a lot as it reduces visual noise- determined through experimentation

IN PROGRESS

Refine the current model – make the compass detection more accurate, ensure it does not get confused with the bolt, figure out a way to integrate everything so it can be used in the final system

NEXT WEEK PLAN

Final object detection refining – ensure it works for the other objects that we have using the data sets collected – implement it

MEMBER 2: Sabeeha Hasham

EVIDENCE (SHOW, DON'T TELL)

•


•

•

•

•

•

HELP NEEDED / QUESTIONS

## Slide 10


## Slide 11

MEMBER 3: Basel Feras Ghunaim

ACCOMPLISHED (SINCE LAST REPORT)

- Completed the gripper mechanical design using a rack and pinion mechanism
- Finalized the V-shaped gripping area for improved handling of small objects
- Completed full CAD design of the gripper, including suction integration
- Designed and aligned the suction mounting system with the gripper tip
- Selected and finalized components:
  - Vacuum pump
  - M5 joint silicone suction cup
  - 4 mm brass barbed connector
- Sent all parts for 3D printing

IN PROGRESS

- Fabrication phase: 3D printing of gripper components
- Preparing for assembly of mechanical and suction systems
- Reviewing design for any last adjustments before testing


NEXT WEEK PLAN

- Receive and assemble printed parts
- Integrate:
  - Gripper mechanism
  - Suction system (pump + tube + suction cup)
- Perform initial functional testing:
  - Gripper opening/closing
  - Suction performance
- Identify and fix any mechanical or alignment issues
- Begin basic control integration

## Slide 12

370 Mini Vacuum Pump

Vacuum pump

4mm Brass Bulkhead Engine Bay To In Car Hose Connector | R-Spec Performance

4mm Brass Barbed Hose Connector


M5 Joint Silicone Vacuum Pneumatic Suction Cup

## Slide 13


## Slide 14

MEMBER 4: Ahmed Alshehhi

ACCOMPLISHED (SINCE LAST REPORT)

•

Researched manual control methods for the robotic arm (joystick-based system and Robot
Shaped miniature control arm).

Identified and listed required components for the control system (Arduino, joystick, wires, potentiometer, etc.)
• Collected approximate prices for all components and compared options.
• Watched and analyzed reference videos to understand implementation.

IN PROGRESS

• Refining component selection based on cost and availability.
• Studying how to connect joystick with Arduino for manual control.

•

NEXT WEEK PLAN

HELP NEEDED / QUESTIONS

•

•

Finalize component list and confirm availability.

Start basic wiring and testing of joystick control system.

•

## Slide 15

WRAP-UP: WHAT WE NEED FROM THE INSTRUCTOR / STAKEHOLDERS

DECISIONS REQUESTED

ACTION ITEMS FOLLOW-UP

- Determine the control method – joystick/app
- Pneumatic integration
- Physical 3d printed prototype so testing can begin
- Refining the computer vision model.

QUESTIONS / FEEDBACK

- https://maherrrrr99.github.io/maherrrrr99/
- https://sabeehahasham.github.io/
- https://basel-ghunaim.github.io/
- https://ahmed1090822.github.io/Ahmed109.github.io/

APPENDIX

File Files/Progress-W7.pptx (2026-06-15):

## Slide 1


WEEKLY PROGRESS REPORT

Mechatronic System Design (MEC483) – Course Project

Maher Abo Abed (1087993) , Sabeeha Zainab Hasham (1089042), Basel Feras Ghunaim (1088912), Ahmad Nasser Alshehhi (1090882)

PROJECT / PHASE

Smart Pick and Place Robot

14/4/2026 – 21/4/2026

DATE RANGE

TEAM MEMBERS

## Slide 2


HOW ARE WE DOING THIS WEEK?

TOP WINS

- Successfully built and tested and IK model using moveit and Rviz for visualizing
- Built, tested and successfully controlled a pneumatic suction system that is capable of relatively high pay loads
- Set up the Raspberry pi with the current yolov8 model, connected and set up the camera – the full system is almost in place

KEY BLOCKERS / RISKS

- Blocker: Continued printing issues – prototype and assembly can’t be made yet, causing significant delays

PROJECT HEALTH

Scope

Under Execution

Schedule

Potential Delays

Fabrication & Prototyping

Under Execution

OPEN ISSUES

3 Active

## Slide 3


Project Schedule (Gantt)

Agile Gantt chart1.xlsx (https://studentsaduac-my.sharepoint.com/:x:/g/personal/1087993_students_adu_ac_ae/IQCVl5X-gnVOTbJbda9AOzVBAQxvkQVJ4Exoq-0edEJwLJE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)


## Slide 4


ISSUES, RISKS, AND ACTION ITEMS

TOP ISSUES (BLOCKING PROGRESS)

- Fabrication delays
- No access to university is slowing down work efforts, and overall progress.

ACTION ITEMS (NEXT 7 DAYS)

ID

A1

ACTION ITEM DESCRIPTION

Finalize and deploy the computer vision model

MEMBER

Sabeeha

WEEK DUE

Week 8

A2

A3

Finish the IK kinematics

Maher

Basel

Week 7

Week 7

MITIGATIONS / DECISIONS NEEDED

- Conduct virtual meetings often.
- Constant communication and updates.
- Each member should take their own initiatives.
- Aim to make any sort of progress, regardless of how small or big.

A4

Procure, assemble, and experiment on gripper.

Finalize a manual override system

Ahmad

Week 7

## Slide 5


INDIVIDUAL UPDATES

WEEKLY PROGRESS & NEXT STEPS

MEMBER 1

Maher Abo Abed

MEMBER 2

Sabeeha Zainab Hasham

MEMBER 3

Basel Feras Ghunaim

MEMBER 4

Ahmad Nasser Alshehhi

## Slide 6

MEMBER 1: Maher Abo Abed

ACCOMPLISHED (SINCE LAST REPORT)

- Finished IK (ROS Based)
  - IKFast – Not successful (older solution, requires almost perfect urdf, visualizing is difficult)
  - Hand calculations – attempted but preferred other solutions
  - Moveit – working, trial and tested, can be visualized
- Analyzed the reachable workspace using this newly made model
- Attempted random poses, and verified solution
- Started with object tracking/following
- Made a successful code, but suffered with hardware issues

EVIDENCE


IN PROGRESS

- Inverse kinematic for the suction
- Object tracking and following
- Awaiting printed parts

NEXT WEEK PLAN

- Mechanical assembly
- Finish the IK
- Finish the object tracking/following.

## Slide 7


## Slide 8


- The program uses a camera to detect objects in real time using a YOLOv8 model.
- It is specifically configured to detect only apples.For every video frame, the model finds objects and filters out everything except apples with sufficient confidence.If multiple apples are detected, the program selects the largest one (closest to the camera)
- It calculates the horizontal position (center) and size (area) of the selected apple.
- The program compares the apple’s position to the center of the screen.
- If the apple is to the left, it sends a "L" command (turn left).If the apple is to the right, it sends a "R" command (turn right).
- If the apple is centered:It sends "F" (move forward) if the apple is far away.It sends "S" (stop) if the apple is close enough.
- Commands are sent through a serial connection to a device like an Arduino.The program avoids sending the same command repeatedly unless it changes.
- It displays the video feed with detection boxes and shows the current target and command on screen.
- The loop runs continuously until the user presses "q" to quit.
- When exiting, it sends a stop command, closes the serial connection, and releases the camera

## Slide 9

MEMBER 2: Sabeeha Hasham

ACCOMPLISHED (SINCE LAST REPORT)

- Installed or worked on camera-related tools (like v4l-utils) for camera support
  - Connected the Raspberry Pi Camera Module 2 to the Pi
- Used Windows PowerShell with the scp command to directly transfer best.zip from my PC to the Raspberry Pi over the network, instead of using file-sharing apps like WhatsApp or Google Drive – they didn’t work
- Attempted to run your object detection system using YOLOv8
- Encountered an error: “Illegal instruction (core dumped)” the model or environment isn't compatible with the Pi setup
- Worked inside a Python virtual environment (yolovenv))
- Adjusted system settings (like memory/swap limits) to improve performance

EVIDENCE (SHOW, DON'T TELL)

•


•

•

•

IN PROGRESS

- Camera is physically connected but the detection code crashes due to compatibility/performance issues

•


HELP NEEDED / QUESTIONS

NEXT WEEK PLAN

•

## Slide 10

MEMBER 3: Basel Feras Ghunaim

ACCOMPLISHED (SINCE LAST REPORT)

- Completed component selection and purchasing process for the suction system Acquired:
  - Vacuum pump
  - Suction cup
  - Tubing and connectors
- Successfully assembled and tested the suction system
- Achieved lifting capability of up to 200 g, exceeding initial requirements
- Validated that the suction system is functional and reliable for target objects

IN PROGRESS

- Evaluating overall system integration (gripper + suction)
- Observing performance and identifying any improvements in stability or sealing
- Discussing control methods for remote operation as a team


NEXT WEEK PLAN

- Explore and implement remote control of the robotic arm/gripper.
- Investigate possible control methods:
  - Wireless control (Bluetooth / Wi-Fi)
  - Remote interface via Raspberry Pi or Arduino
- Select the most suitable approach and begin initial implementation and testing

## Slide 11

- Looked into basic Arduino connections for joystick control
- Reviewed simple circuit examples to understand wiring layout.

- Begin assembling the control components.
- Start initial testing of joystick input with Arduino.

MEMBER 4: Ahmed Alshehhi

ACCOMPLISHED (SINCE LAST REPORT)

IN PROGRESS

- Preparing the wiring setup for the joystick and Arduino
- Understanding signal mapping between joystick input and motor movement

NEXT WEEK PLAN

HELP NEEDED / QUESTIONS

•

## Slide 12

WRAP-UP: WHAT WE NEED FROM THE INSTRUCTOR / STAKEHOLDERS

DECISIONS REQUESTED

ACTION ITEMS FOLLOW-UP

- Determine the control method – joystick/app
- Pneumatic integration
- Physical 3d printed prototype so testing can begin
- Refining the computer vision model.

QUESTIONS / FEEDBACK

- https://maherrrrr99.github.io/maherrrrr99/
- https://sabeehahasham.github.io/
- https://basel-ghunaim.github.io/
- https://ahmed1090822.github.io/Ahmed109.github.io/

APPENDIX

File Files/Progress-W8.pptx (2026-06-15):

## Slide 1


WEEKLY PROGRESS REPORT

Mechatronic System Design (MEC483) – Course Project

Maher Abo Abed (1087993) , Sabeeha Zainab Hasham (1089042), Basel Feras Ghunaim (1088912), Ahmad Nasser Alshehhi (1090882)

PROJECT / PHASE

Smart Pick and Place Robot

21/4/2026 – 28/4/2026

DATE RANGE

TEAM MEMBERS

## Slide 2


HOW ARE WE DOING THIS WEEK?

TOP WINS

- Successfully built and tested and IK model using moveit and Rviz for visualizing
- Built, tested and successfully controlled a pneumatic suction system that is capable of relatively high pay loads
- Set up the Raspberry pi with the current yolov8 model, connected and set up the camera – the full system is almost in place

KEY BLOCKERS / RISKS

- Blocker: Continued printing issues – prototype and assembly can’t be made yet, causing significant delays

PROJECT HEALTH

Scope

Under Execution

Schedule

Potential Delays

Fabrication & Prototyping

Under Execution

OPEN ISSUES

3 Active

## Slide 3


Project Schedule (Gantt)

Agile Gantt chart1.xlsx (https://studentsaduac-my.sharepoint.com/:x:/g/personal/1087993_students_adu_ac_ae/IQCVl5X-gnVOTbJbda9AOzVBAQxvkQVJ4Exoq-0edEJwLJE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)


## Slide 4


ISSUES, RISKS, AND ACTION ITEMS

TOP ISSUES (BLOCKING PROGRESS)

- Fabrication delays
- Assembly and physical testing can be started

ACTION ITEMS (NEXT 7 DAYS)

ID

A1

ACTION ITEM DESCRIPTION

TBD

MEMBER

Sabeeha

WEEK DUE

Week 8

A2

A3

TBD

Maher

Basel

Week 8

Week 8

MITIGATIONS / DECISIONS NEEDED

- Printing supervision- problem is we were informed printers are not working in AD

A4

TBD

TBD

Ahmad

Week 8

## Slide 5


WEEKLY PROGRESS & NEXT STEPS

GROUP UPDATE

MEMBER 1

Maher Abo Abed

MEMBER 2

Sabeeha Zainab Hasham

MEMBER 3

Basel Feras Ghunaim

MEMBER 4

Ahmad Nasser Alshehhi

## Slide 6


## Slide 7


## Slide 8

WRAP-UP: WHAT WE NEED FROM THE INSTRUCTOR / STAKEHOLDERS

DECISIONS REQUESTED

ACTION ITEMS FOLLOW-UP

- Mechanical and electrical assembly
- Sub-systems integration (vision/following/kinematics)
- Platform design
- More simulations, tests and runs

QUESTIONS / FEEDBACK

- https://maherrrrr99.github.io/maherrrrr99/
- https://sabeehahasham.github.io/
- https://basel-ghunaim.github.io/
- https://ahmed1090822.github.io/Ahmed109.github.io/

APPENDIX

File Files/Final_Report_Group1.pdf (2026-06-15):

College of Engineering

Spring 2025-2026

Course Name and code | MEC483 – Mechatronics System Design
Instructor | Dr. Claudio Vignola
Assignment/ Project Title and number | Group Project – Autonomous Pick & Place Robot
Due date | 15 June 2026
Submission Date | 15 June 2026
| 1. Maher Abo Abed | 1087993
| 2. Sabeeha Zainab Hasham | 1089042
| 3. Basel Feras | 1088912
| 4. Ahmed Nasser Alshehhi | 1090822

Submitted by:

Student Name
Student ID
Signature

Table of Contents

6.2 | Base Platform | 41
6.3 | Dimensions and Workspace Envelope | 42
7. Inverse Kinematic Narrative | 43
7.1 | Robot Modelling and MoveIt Setup | 43
7.2 | Resolving Initial IK Failures | 47
7.3 | Position-Only IK and Workspace Validation | 47
8. Version 2.0 and Lesson Learned | 49
9. References | 51
10. Appendix | 52

Table of Figures

Figure 1-1: Business Model Canvas for the Pick and Place Robot | 1
Figure 3-1: Initial Gantt chart | 7
Figure 4-1: The final electrical block diagram of the system | 8
Figure 4-2: All the hardware parts used in the making of the robotic arm | 9
Figure 4-3: Simulations with a payload of 250g confirm the choice of the motors | 16

Figure 4-4: Electrical schematic of the system. Red shows 12-6 V power lines, black is for

ground, blue is for servos signal lines, and orange is for 5 V VCC line | 19
Figure 5-1: Egg (left) and Nut (right) Datasets used for Detection | 20
Figure 5-2: Bounding Box Annotations used for Training | 22
Figure 5-3: Txt File for Egg Detection (1) | 23
Figure 5-4: YOLOv8 Training using PyCharm in a Custom Dataset | 24
Figure 5-5: HSV Calibration Tool for Green Object Detection | 25
Figure 5-6: Successful Detection During Live Camera Testing of the Trained Model | 27
Figure 5-7: YOLOv8 Model Deployed on the Raspberry Pi | 28
Figure 5-8: Green ball detection with distance estimation | 34
Figure 5-9: Compass detection with distance estimation | 34
Figure 5-10: Entry page of the Pick and Place Robot Controller | 35

Figure 5-11: Robot Operation Center showing connection state, operation modes, and safety

controls | 36
Figure 5-12: Manual Arm and Manual Platform control panels | 37
Figure 5-13: Camera stream, command log, and robot status panel | 38
Figure 6-1: Circular servo horn used for the joint fitting | 39

Figure 6-2: 3D CAD render of the robotic arm in SolidWorks | 40
Figure 6-3: 3D CAD render of the gripper mechanism | 40
Figure 6-4: Physical assembly of robotic arm | 41
Figure 6-5: Fully assembly robotic arm attached to the platform | 42

Figure 7-1: SolidWorks used to define joint axis and create the URDF model based on the CAD

assembly | 44
Figure 7-2: Defining the kinematic chain | 44
Figure 7-3: Defining joint limits for the URDF model | 45
Figure 7-4: MoveIt2 Setup Assistant | 45
Figure 7-5: Configuring the MoveIt2 solver | 46

Figure 7-6: Independent control of individual joints using sliders to determine angular position...... 46

Figure 7-7: Workspace scan to validate inverse kinematic solver | 48

Table of Tables

Table 2-1: Pick and Place Robot Project Criteria | 3
Table 2-2: Constrains within the Project | 4
Table 4-1: Summary of all the components used and their function in the system | 9
Table 4-2: Weighted decision matrix - microcontroller selection | 11
Table 4-3: Weighted decision matrix - camera selection | 12
Table 4-4: Weighted decision matrix - minicomputer selection | 14
Table 4-5: Decision matrix - robotic arm actuator | 15
Table 4-6: Power budget summary | 17
Table 6-1: Robot footprint and arm reach envelope | 43
Table 7-1: Sample of confirmed reachable workspace points | 48

### 1. Business Model Canvas

The business model canvas was developed in order to evaluate the commercial feasibility and

potential implementation strategy of the proposed Pick and Place Robotic System. The canvas

identifies the key stakeholders, resources, activities and value propositions required to

successfully develop and maintain the system. A structured overview of how the project can

create value for customers whilst maintaining financial performance was provided. The model

considers both the technical capabilities of the system alongside the practical requirements for

its deployment within manufacturing, logistics and potential educational environments.


Figure 1-1: Business Model Canvas for the Pick and Place Robot

The analysis demonstrates that the proposed system offers value through automation, improved

operational consistency, and the reduced dependence on manual labour. The identified

customer segments can indicate the potential applications across a series of disciplines such as

manufacturing, packaging, logistics and educational sectors. Strategic partnerships with

component suppliers, automation integrators and educational institutions support both the

system development and future scalability. The revenue streams and cost structure suggest a

more feasible pathway for commercialization through system sales, integration services and

support contracts that will be ongoing. The design provides a foundation for future

enhancements such as higher speed operations and additional object classes; this system

supports growing technological fields through intelligent automation and data driven decision making. Overall, the business model canvas highlights the potential of the pick and place

robotic system to evolve simply from a prototype into a more practical automation solution for

a range of industrial and educational applications.

### 2. Problem Definition

2.1 Final Problem Statement

The modern manufacturing and automation systems demand fast, accurate and reliable object

handling process. Manual pick and place operations can be slow, and human errors are more

susceptible to occur, they are also not suitable for repetitive high precision operations. In

addition, traditional robotic systems are typically designed to work with objects in a fixed

location, and they cannot adapt to changing environments.

To tackle these challenges, this project proposes to build a Smart Pick and Place Robotic

System with computer vision integrated within it. The system is aimed at automatically

identifying objects in a workspace, locating their positions and operating a robot arm to pick

and place the objects without any human intervention. The system combines sensing, image

processing, embedded control and mechanical actuation offering a smart and efficient

automation solution.

2.2 Final Impact Statement

The developed system shows the application of mechatronic engineering principles with the

integration of mechanical, electrical, control and computer engineering subsystems. The

combination of computer vision in the robotic arm enhances the precision of object detection

and reduces reliance on manual handling, improving both accuracy and efficiency.

The project helps to understand the latest automation technologies utilized in manufacturing,

warehousing, packaging and assembly processes. Moreover, the platform developed will serve

as a basis for future developments like advanced object recognition and fully autonomous

industrial robotic systems.

### 2.3 Criteria

Table 2-1: Pick and Place Robot Project Criteria

Criteria | Rationale | Electrical
| | Implementation

Software

Implementation

Mechanical

Implementation

CR-1: Object Detection Accuracy | Ensure reliable
| object
| identification | Stable camera
| | power and
| | communication
| | interfaces

Computer vision

algorithm detects

and identifies

objects

Proper camera

positioning and

workspace setup

CR-2: Pick-

and-Place

Success Rate

Evaluate

overall system

effectiveness

Reliable motor

drivers and

actuator control

circuits

Accurate object

coordinate

processing

Stable robotic arm

structure and

gripper design

CR-3:

Positioning

Accuracy

Ensure precise

object

placement

Stable power

delivery

Calibration of each

component

Accurate joint

assembly and

minimized

mechanical

tolerances

CR-4:

Response

Time

Improve

operational

efficiency

Fast signal

transmission

between

components

Efficient image

processing and

serial

communication

Smooth robotic arm

motion with

minimal delay

CR-5:

Payload

Capacity

Ensure

practical

object

handling

capability

Motors supplied

with adequate

voltage and

current

Motion control

adapted to payload

requirements

Strong arm

structure and

gripper mechanism

CR-6:

Repeatability

Consistent

performance

over multiple

cycles

Stable electrical

operation and

sensor readings

Repeatable control

commands and

calibration

procedures

Rigid joints with

minimal backlash

CR-7:

Workspace

Coverage

Ensure

sufficient

reach within

workspace

Proper actuator

selection and

power distribution

Workspace

mapping and

coordinate

transformation

Arm dimensions

optimized for

maximum reach

### 2.4 Constraints

Table 2-2: Constrains within the Project

Constraints | Rationale | Electrical
| | Implementation

Software

Implementation

Mechanical

Implementation

CO-1: Prototype Budget | Limited student
| project budget | Cost-effective
| | electronic
| | components selected

Open-source

software tools used

Low-cost

manufacturing

materials used

CO-2: Power Supply | Provide stable
| operation of all
| subsystems | 6V for motors and
| | 5V for electronics
| | using buck
| | converters

Stable operation of

vision and control

software

Supports actuator

and sensor

requirements

CO-3:

Microcontroller

Required embedded

control platform

Arduino controls

motors and sensors

Communication with

vision system

Interfaces with

robotic arm actuators

CO-4: Computer

Vision Integration

Enable autonomous

object recognition

Servo motors

connected to

Arduino outputs

Motion control

routines

implemented

Robotic arm joints

actuated for

movement

CO-5: Actuators

Controlled by

Microcontroller

Enable robotic arm

motion

Servo motors

connected to

Arduino outputs

Motion control

routines

implemented

Robotic arm joints

actuated for

movement

CO-6: Serial

Communication

Transfer | data
between | vision

system and controller

USB communication

interface

Python-Arduino

communication

implemented

Supports coordinated

arm movement

CO-7:

Manufacturing

Method

Limited fabrication

resources

Proper mounting of

electronics

Software compatible

with hardware layout

Laser-cut platform

and fabricated arm

components

CO-8: Safe

Operation

Ensure | safe

laboratory operation

5V and 6V regulated

power supplies

Software | limits
prevent | unsafe

movements

Stable structure and

safe moving parts

CO-9: Project

Timeline

Course requirement | Electronics

integrated on

schedule

Software tested and

debugged | on

schedule

Mechanical assembly

completed on

schedule

### 3. Project Management Overview

### 3.1 Team Members Responsibilities & Accomplishments

Maher Abo Abed:

Maher Abo Abed was the project's group leader, responsible for monitoring the progress of the

project and the embedded systems, electrical and mechanical integration work. Electrically,

Maher did the wiring for the system, which involved connecting the common ground between

the microcontroller, the servo driver, the motor driver and the external power supply, after

determining that the electrical supply sagged when the servos were loaded, necessitating the

use of a separate power supply for the servo and motor rails. Maher adjusted each arm joint

individually for motor configuration, from angle-based to direct pulse-width control for finer

adjustment. He set the working pulse ranges for the elbow and wrist (including correcting for

the non-standard dead zone of the wrist) and solved servo jitter on unused driver channels while

creating a serial command interface for fast, iterative calibration. Maher programmed the

firmware for joint control, encoder reading, motor driving and a GUI for joint control via serial.

He also worked on the inverse kinematics development using ROS 2 and MoveIt 2, creating

the kinematic model of the arm, configuring the MoveIt planning pipeline, fixing the IK solver

problems that initially prevented the IK, and testing the arm's workspace with a custom

scanning node. In manufacturing and assembly, Maher designed and 3D printed the arm's links

and joints using PLA, as well as the servo mounts and gripping/suction mechanism. In the

process, he discovered that the originally designed shoulder joint was redundant with the

steering capability of the mobile base, and reduced the arm to a 3-DOF manipulator. He also

cut the chassis from acrylic with a laser and mounted the motors, arm and electronics on it.

During the project, Maher performed a significant amount of testing at the subsystem and

system level, individual servo and joint calibration, motor and encoder testing, workspace

reachability testing, and integration testing of the wireless control link, and coordinated the

team's documentation (including the hardware design, component selection, power budget, and

inverse kinematics sections of the final report).

Sabeeha Hasham:

Sabeeha Hasham’s main role within this project was the vision detection system, this involved

obtaining the dataset alongside training and annotating the images that were taken. She focused

on making HSV work for one of the objects and perfecting the dataset for the remaining four

objects, this was carried out by selecting an appropriate camera and connecting it alongside

uploading the trained YOLOv8 model to the Raspberry Pi therefore enabling the set to be tested and issues like lagging and sensitivities to be altered based on the requirements of the project.

The images taken were manually annotated and categorized into her laptop to then be trained

over 100 cycles ensuring that the model understood the bounding regions of the object in a

series of different environments. Issues were faced with the camera selection as with the Pi

Camera, viewing the output on the pi was not successful therefore it had to be changed,

continuous issues with the model were faced as well. Throughout the end of the process where

integrating the components together had to occur, she had some involvement in the testing

alongside mitigating further issues faced. The various resources and software used throughout

this project were: Anaconda, PyCharm, Ubuntu, CVAT, PowerShell, OpenCV in order to train

the set and obtain images from open source resources alongside transferring resources such as

the best.pt file required for identification of the objects within a space.

Basel Feras Ghunaim:

Basel Feras Ghunaim designed and controlled the suction system, designed the gripper,

designed the distance estimation pipeline using the camera, designed the wireless

communication link, designed the project website, and did some aspects of system integration

and testing. Basel developed the pneumatic circuit and chose the air pump for the suction

system and began to work on the control of the air pump. After testing the pump with a

MOSFET, he decided to use a relay as the switching device as it was more reliable and easier

to control. He also created the rack and pinion gripper mechanism that is used in conjunction

with the suction cup in the hybrid end effector. On the computer vision side, Basel developed

an object-tracking model that allows them to calculate the distance of an object detected by the

camera from the camera itself. This included increasing the training set to make it more robust

for detection, and using reference images to calibrate the relationship between the apparent size

of the object in the image and the distance of the object in real life, then using mathematical

formulas based on this calibration to translate the size measured in the image into the distance

to the object. For the streaming pipeline, Basel fine-tuned the frame rate, quality and resolution

of the camera stream to optimise the accuracy of the detection versus the processing time, and

set up the Raspberry Pi to act as a Wi-Fi bridge between the camera, the detection system and

the rest of the network. Basel handled the wiring and configuration of the HC-05 module to

create the Bluetooth communication link between the Arduino and the control system,

collaborating with Maher to configure the module and connect the robot to the operator's

computer to allow the exchange of commands and status updates between the two wirelessly.

Basel also designed, developed, and integrated the project's control website, while Maher was involved in its implementation. Basel has played a key role in testing and experimentation at

the component and system level throughout the project, provided overall system integration

support, and made a contribution to the project documentation.

Ahmed Alshehhi:

Ahmed Alshehhi was involved in the design of the control system application and the

integration of the project subsystems in order to make sure that the hardware and software

components are communicating seamlessly. He helped to wire the electronic components,

check the systems connections and help with the overall integration process. Additionally,

Ahmed was involved in project file management and collaboration using GitHub, ensuring that

project files and documentation remain organized and version controlled.

He also helped make 3D printed components and assembly of the robotic arm structure.

Engaged in system trials, testing, and troubleshooting to assess the performance of prototypes

and make revisions. Ahmed also helped in the documentation of the project throughout and the

preparation of the final report.

### 3.2 Gantt Chart


Figure 3-1: Initial Gantt chart.

### 4. Hardware Design Narrative

This section covers the hardware side of the project: how the wiring is laid out, what each part does,

why we picked the parts we did, and how power is supplied and budgeted across the system. At a high

level, the robot is made up of four pieces working together: a wheeled base that moves the robot around, a 4-jointed arm that picks things up, a camera-based vision system that finds objects, and a wireless

link that lets us send commands and see what the robot sees.

### 4.1 Final Electrical Block Diagram


Figure 4-1: The final electrical block diagram of the system.

The above figure gives an overview of how the different components are connected to each

other. A 12V battery supply is sent through a step-down buck converter to reduce the voltage

to 6V. The output of the buck converter is used to power the relay through the COM port, the

PCA9685 driver, pump, and the l298N motor driver which operates two dc motors. Another

line is used which has a power rating of 5V, this power line is used as a source for the Arduino

and Raspberry Pi. This voltage comes from a regulated source. 5V is also used for all the signal

lines (VCC/IN), this is seen in the relay, HC05, and PC9685. All the components are grounded

to one common ground as to keep the signal clean and reduce any electrical noise.

### 4.2 Detailed Hardware Description


Figure 4-2: All the hardware parts used in the making of the robotic arm.

Table 4-1: Summary of all the components used and their function in the system.

No. | Component | What It Does in the System

1

12 V Power Source

(Li-ion Battery Pack)

The main battery. It powers the buck converter, which

then supplies the actuators, relay and pump.

2

5 V Power Source

(Power Bank)

Gives Raspberry Pi and Arduino its own steady 5 V

supply, so it does not lose power when the servos or

motors draw a lot of current.

3

Buck Converter (12

V → 6 V)

Steps the 12 V battery voltage down to a steady 6 V for

the actuators, relay and pump.

4 | Arduino Uno

The main controller. It reads the signals and data input,

sends commands to the servos through the driver board,

and drives the two-wheel motors.

5 | Raspberry Pi 4

Used as bridge between the camera and the laptop, to

run YoloV8 (computer vision model).

HC-05 Bluetooth

Module

A wireless link between the Arduino and the computer

running the dashboard, used to send commands and

receive status updates.

5 V Relay Module

Acts as a switch that the Arduino uses to turn the air

pump on and off.

PCA9685 16-Channel

Servo Driver

Generates the signals needed to control the three arm

servos (wrist, elbow, gripper), freeing up the Arduino's

limited number of pins.

L298N Motor Driver

Provides enough current to drive the two wheel motors,

since the Arduino's pins cannot supply that much power

on their own.

DC Air Pump

Creates suction for the gripper's suction cup, allowing it

to pick up objects.

DC Motor 1 (with

encoder)

Drives the left wheel of the mobile base. The encoder

lets the Arduino know how fast and how far the wheel

has turned.

DC Motor 2 (with

encoder)

Drives the right wheel of the mobile base, with the same

encoder feedback as Motor 1.

MG995 Servo Motor

1

A strong servo used for the wrist joint of the arm.

MG995 Servo Motor

2

A strong servo used for the elbow joint of the arm.

Servo Motor 3

(SG90)

A smaller, lighter servo used to open and close the

gripper.

Logitech C270

Webcam

The camera used for object detection , both the

YOLOv8 model and the colour-based detection rely on

this camera's video feed.

Suction Cup

The part of the gripper that actually touches and holds

onto objects, using suction from the air pump.

Brass Tee Fitting

A small fitting that connects the air pump's tubing to the

suction cup line.

### 4.3 Final Major Component Selection Rationale

To make sure that all decisions made are as objective as possible, a systematic approach was

taken to choose the major components in the system. This includes the microcontroller, the

actuators, the onboard computer, and the camera. Every selection was based on a weighted

criteria and a score from 1 (worst) to 5 (best). The scores are commutatively added and the

choice with the highest score is the decision that team is going with.

### 4.3.1 Microcontroller Selection

A comparison was dawn between the Arduino UNO against two other common

microcontrollers, those being the STM32 Nucleo and the ESP32. Both the boards competing

with the Arduino possess faster speeds and memory; however, the nature of the project does

not require such power. The tasks require are simple and can be handled by an Arduino. The

most critical criteria was familiarity, availability, and experience. The group used Arduino IDE

before and are well accustomed with how it operates. Furthermore, there are well-tested

libraries/resources online. For these reasons the Arduino was selected [1], [2], [3].

Table 4-2: Weighted decision matrix - microcontroller selection.

Criteria | Weight
Arduino | STM32 | ESP32
Uno | Nucleo | Dev Board

Price (Arduino ~92

AED | vs | STM32
~55–92 | AED | vs
ESP32 | ~22–37

AED)

0.20 | 4 | 3 | 5
Processing Speed | 0.10 | 2 | 5 | 4

Matches 5 V Logic

of | Servo/Motor
Drivers | 0.20 | 5 | 3 | 2
Library | and

Community Support

0.20 | 5 | 3 | 4

Ease of Setup (no

extra | circuitry,

familiar IDE)

0.20 | 5 | 2 | 3

Built-in | Wireless
(not | needed. | Use

HC-05)

0.10 | 2 | 2 | 5
Weighted Score | 1.00 | 4.20 | 2.90 | 3.70

### 4.3.2 Camera Selection

The camera options were explored for the computer vision subsystem: Logitech C270 webcam,

Raspberry Pi Camera Module V2, and a generic InnoMaker USB camera. In theory, both

options are superior; the Pi Camera and InnoMaker both offer 1080p while the InnoMaker

camera has a much larger field of view. The biggest factor was that the team already had a

Logitech C270 so using it meant both time and cost was saved. Not only is the C270 a standard

USB camera that works with OpenCV on Windows and Linux without any special drivers, but

it also solved the driver problems that were encountered when attempting to get the Pi Camera

to work on Ubuntu. Its 720p video is more than adequate for the object detection model and

the color detection used so the additional resolution and field of view of the other cameras

wasn't worth the additional cost and setup time [4], [5], [6].

The camera options were explored for the computer vision subsystem: Logitech C270 webcam,

Raspberry Pi Camera Module V2, and a generic InnoMaker USB camera. In theory, both

options are superior; the Pi Camera and InnoMaker both offer 1080p while the InnoMaker

camera has a much larger field of view. The biggest factor was that the team already had a

Logitech C270 so using it meant both time and cost was saved. Not only is the C270 a standard

USB camera that works with OpenCV on Windows and Linux without any special drivers, but

it also solved the driver problems that were encountered when attempting to get the Pi Camera

to work on Ubuntu. Its 720p video is more than adequate for the object detection model and

the color detection used so the additional resolution and field of view of the other cameras

wasn't worth the additional cost and setup time [4], [5], [6].

Table 4-3: Weighted decision matrix - camera selection.

Criteria

Weight | Raspberry
| Pi Camera
| V2

InnoMaker

USB

Camera

Logitech

C270

Image Quality

(5%)

0.05
4 | 4 | 3

Ease | of

Integration

(25%)

0.25

2 | 4 | 5
Availability | &

Cost (40%)

0.40
1 | 1 | 5

Software

Compatibility

(25%)

0.25

2 | 4 | 5
Reliability (5%) | 0.05 | 4 | 3 | 4
Total Score | 1.00 | 1.80 | 2.75 | 4.85

### 4.3.3 Mini-Computer (Vision Process) Selection

Raspberry Pi 4 was compared with the NVIDIA Jetson Nano and the FriendlyElec NanoPi M4

for running the object-detection software. The built-in graphics chip makes the Jetson Nano's

processor much faster at AI jobs, while the NanoPi M4 is also faster on paper. The Raspberry

Pi 4, however, is about a third of the price of the Jetson Nano (around 128–202 AED versus

363 AED) and has Wi-Fi and Bluetooth built in, meaning that there was no need for extra

wireless equipment, and there is much more documentation and example code available for

running OpenCV and Flask on the RPi 4. The object-detection model was found to be fast

enough to run comfortably on the Pi 4's processor at the speed of dashboard updates (250 ms),

and the same was true of the color detection. The Jetson Nano's extra processing power wasn't

needed for this application [7], [8], [9].

Raspberry Pi 4 was compared with the NVIDIA Jetson Nano and the FriendlyElec NanoPi M4

for running the object-detection software. The built-in graphics chip makes the Jetson Nano's

processor much faster at AI jobs, while the NanoPi M4 is also faster on paper. The Raspberry

Pi 4, however, is about a third of the price of the Jetson Nano (around 128–202 AED versus

363 AED) and has Wi-Fi and Bluetooth built in, meaning that there was no need for extra

wireless equipment, and there is much more documentation and example code available for

running OpenCV and Flask on the RPi 4. The object-detection model was found to be fast

enough to run comfortably on the Pi 4's processor at the speed of dashboard updates (250 ms),

and the same was true of the color detection. The Jetson Nano's extra processing power wasn't

needed for this application [7], [8], [9].

Table 4-4: Weighted decision matrix - minicomputer selection.

Criteria | Weight

Raspberry

Pi 4 (4

GB)

NVIDIA

Jetson

Nano (4

GB)

FriendlyElec

NanoPi M4

Price (Pi 4 ~128–

202 AED vs Jetson

Nano ~363 AED vs

NanoPi M4 ~184–

275 AED)

0.25 | 5 | 1 | 2
Processing | Power

for Object Detection

0.20 | 3 | 5 | 4
Built-in | Wi-

Fi/Bluetooth

0.15 | 5 | 1 | 3

Documentation and

Community Support

0.20 | 5 | 3 | 2
Pin | Compatibility

with

Sensors/Modules

0.10 | 5 | 4 | 4
Power Use and Heat | 0.10 | 5 | 2 | 3
Weighted Score | 1.00 | 4.60 | 2.60 | 2.85

### 4.3.4 Arm Actuator

Three different types of motor were tested: servos (e.g. MG995, SG90), brushed DC motors,

and stepper motors. The primary reason for selecting servos was because they already had a

built-in position sensing system; a DC motor or stepper would have needed another sensor (an

encoder) to do the same. Servos also share a single signal wire with the servo driver board

already installed in the system, while DC motors have to have a separate motor driver circuit

and stepper motors must have a dedicated driver chip. Servos were chosen for the wrist, elbow

and gripper for this project because of the simplicity of wiring, the built-in position feedback,

and a torque output that was more than enough for the arm, although they were not as precise at positioning as stepper motors, and DC motors with gearboxes would be cheaper and still

provide strong continuous torque [10], [11].

Table 4-5: Decision matrix - robotic arm actuator.

Criteria | Weight

Servo

(MG995/SG90)

DC Motor

+

Gearbox

Stepper

Motor

Knows Its Own

Position (no extra

sensor needed)

0.25 | 5 | 1 | 4
Simple | Wiring

(plugs into servo

driver vs. needs

its | own | driver

circuit)

0.20 | 5 | 2 | 2

Torque for the

Price (MG995:

~11 kg·cm at 6 V,

~29–51 AED)

0.20 | 4 | 4 | 3
Price | per | Unit

(MG995 ~29–51

AED | vs | DC
motor | ~11–22

AED vs stepper

~37–73 AED)

0.15 | 3 | 5 | 2

Holds Its Position

with No Power

Applied

0.10 | 5 | 1 | 5
Speed | of

Movement

0.10 | 3 | 5 | 2
Weighted Score | 1.00 | 4.30 | 2.80 | 3.00

### 4.4 MG995 Torque Sizing for the Arm

The wrist and elbow joints were chosen to use the stronger MG995 (rated around 3 kg·cm)

servo instead of the lighter MG900 (rated around 1.8 kg·cm) as these two joints are the most

loaded when the arm is fully stretched out to reach an object. The MG995 is rated at roughly

11 kg·cm of torque at 6 V, rising to about 13 kg·cm at 7.2 V . To prove this, a simple simulation

of the fully extended arm was performed by adding the weight of the forearm, the gripper and

a representative object (an egg, nut, bolt or ball). As seen in the figure below, the torque

produced by the actuators is more than sufficient and can be used for safe operations.


Figure 4-3: Simulations with a payload of 250g confirm the choice of the motors.

### 4.5 Power Supply Selection

Power is arranged in three voltage levels. The 12 V line is the raw battery line that is fed into a

buck converter that reduces the voltage to 6 V. This 6 V rail is used to power the V+ pins of the

PCA9685 servo driver, which then powers all three arm servos, and also powers the the DC air

pump (via the relay) and the two wheel motors (via the L298N). The logic/signal line (5 V)

provides the VCC of the Arduino, the Raspberry Pi, the Bluetooth module, the signal side of

the PCA9685, and the signal/logic side of the L298N motor driver and the relay module. The

5 V logic rail is isolated from the 6 V/12 V power rail so that a sudden surge in current from

the servos, motors or pump does not cause a voltage drop that could reset the Arduino or the

Raspberry Pi. As illustrated in Figure 4-1, all of the grounds, including the 12 V battery, the 6

V buck converter output, the 5 V rail, the Arduino, the Pi, and all other modules, are connected

together on one common ground bus. This prevents electrical noise from the high current

wiring for the motors, pump, and servos from interfering with the signal wiring. The 12 V rail

is powered directly by the main battery pack, which has a capacity of 12 V, 3000 mAh (36 Wh).

The switching buck converter is used rather than a linear regulator to step down the 12 V to the

6 V required by the servos, motors and pump which draw several amps at peak load, because

the 12 V to 6 V conversion with a linear regulator would dissipate a significant amount of

energy as heat. A switching buck converter will convert at greater than 85% efficiency and will

not overheat like linear regulators do when operating under this type of load.

### 4.6 Power Budget

The current used by each component of the system is shown in table below at the voltage at

which it operates. This is used to size the battery and to ensure the buck converter and motor

driver don't have to deliver more current than they are rated for. The servo numbers are worst

case (stall) numbers, as if all three servos are pushing against something at the same time, the

DC motor numbers are typical running numbers, not stall numbers.

Table 4-6: Power budget summary.

Subsystem | Supply Voltage | Typical Current | Peak Current | Power (Peak)
Arduino Uno (logic) | 5 V | 50 mA | 80 mA | 0.40 W
HC-05 Bluetooth Module | 5 V | 30 mA | 40 mA | 0.20 W

PCA9685 Driver

(logic/signal)

5 V | 10 mA | 15 mA | 0.075 W

MG995 Servo

(Wrist)

6 V (via

PCA9685 V+)

170 mA | 2.0 A | 12.0 W

MG995 Servo

(Elbow)

6 V (via

PCA9685 V+)

170 mA | 2.0 A | 12.0 W

SG90 Servo

(Gripper)

6 V (via

PCA9685 V+)

100 mA | 650 mA | 3.9 W

L298N Motor Driver

(logic)

5 V | 36 mA | 70 mA | 0.35 W

DC Motor 1 (mobile

base)

6 V (via

L298N)

300 mA | 1.2 A | 7.2 W

DC Motor 2 (mobile

base)

6 V (via

L298N)

300 mA | 1.2 A | 7.2 W
DC Air Pump | 6 V (via relay) | 250 mA | 400 mA | 2.4 W

Subsystem | Supply Voltage

Typical

Current

Peak

Current

Power

(Peak)

5 V Relay Module

(coil)

5 V | 70 mA | 70 mA | 0.35 W
Raspberry Pi 4 | 5 V | 600 mA | 1.2 A | 6.0 W
Total 6 V Rail | 6 V | 1.29 A | 7.45 A | 44.7 W
Total 5 V Rail | 5 V | 0.80 A | 1.48 A | 7.4 W

If all three servos stall at the same time, and both wheel motors and the air pump are operating

at full power, then the 6 V rail has to draw about 44.7 W from the 12 V battery, which is about

7.45 A, considering the efficiency of the buck converter (around 85%). This equates to a worst-

case scenario of 41 minutes if this load were to be maintained continuously, but this is not

likely to be the case in normal operation as servos and motors are not expected to stall

simultaneously for long periods. The 6 V rail consumes approximately 7.74 W, which would

represent approximately 0.76 A from the 12 V battery, resulting in an estimated run time of

about 4 hours enough for development, testing and demonstration sessions. The 6 V rail peak

current is 7.45 A, which is much larger than the average current (1.29 A), so the buck converter

and wiring should be capable of handling at least 8 A.

### 4.7 Final Electrical Schematic

The figure below is an electrical schematic showing how different components are wired

together, and what was connected to the individual ports of each component.


Figure 4-4: Electrical schematic of the system. Red shows 12-6 V power lines, black is for ground, blue is for servos signal lines, and orange is for 5 V VCC line.

### 5. Software Design Narrative

### 5.1 Software Design Rationale

### 5.2 Vision Detection System

A vision detection system was developed in order to provide real-time object recognition

enabling tracking which is vital for the system to run autonomously. This system combines

deep learning-based detection using YOLOv8 with image processing techniques utilized such

as HSV color filtering to improve reliability under different conditions. The development

process included dataset acquisition, image annotation, model training, sensitivity tuning,

camera integration and the performance validation through a series of testing. The trained

model was then deployed onto the Raspberry Pi 4 and integrated with the camera system to

allow embedded operation without the need for external connections and computing resources.

Additional testing was conducted to test detection accuracy, latency, connectivity and

performance to understand how useful it was when tested under conditions similar to the final test. The complete development process is discussed from the dataset preparation to model

training and system testing.

### 5.2.1 Dataset Acquisition

As it is required to detect 5 objects such as an egg, nut, bolt, compass and ball, it is vital to

obtain datasets which can later be used for the process involved in training the model.

The dataset consisting of egg images were obtained from the Open Images Dataset as it

provides a large collection of images suitable for model training applications. This tool was

used to identify and download images with a diverse set of samples with varying backgrounds,

lighting conditions, object orientations and types of eggs. The way in which these were taken

from the website was through the software Anaconda, the object class “egg” was specified as

the search target with 100 specified as the amount of photos taken from the set. An organized

folder consisting of these images was created and stored. Duplicated or invalid images were

filtered out to improve overall dataset quality and error handling routines were included to

remove corrupted image files. The compass detection was made of images that were taken

manually under different lighting conditions and backgrounds, these were manually annotated

and incorporated within the rest of the dataset.

For the nut and the bolt, these datasets were partially created manually and partially obtained

from online resources. This is useful to ensure that images consisting of different lighting was

used alongside having images with many bolts and nuts as opposed to just one, however the

dataset was partially manually created as it allows the trained model to identify the specific

model that will be used. The website Roboflow was used to obtain the dataset, and a similar

process was used to filter images, unclear images or overcrowded images were removed and

replaced with more reasonable images that will aid the dataset in identifying it. The following

figure displays the datasets used for the egg and bolt detection.

Figure 5-1: Egg (left) and Nut (right) Datasets used for Detection

The collected datasets provided a broad range of images related to each object enabling the

model to learn distinguishing features over different viewing conditions and environments.

Variation is highly crucial within the dataset for improving model generalization and

decreasing the sensitivity to changes related to lighting, scale and orientation. The dataset

formed a foundation for the training pipeline with high image quality and diversity playing an

important role within the accuracy of the model. Dataset organization and management was

carried out later to facilitate efficient annotation and validation, allowing for a smooth

transition to the testing process.

### 5.2.2 Image Annotation and Labelling

During the process of training of the model, it is required to annotate the training data to allow

the model to identify the target object and location within an image. Annotation is extremely

crucial to expose the model to truth information which is vital for training and allowing the

model to associate image features with an object class. Bounding boxes were used to define

the position of each object allowing the model to learn classification and localisation tasks.

Accurate annotations allow for achieving high detection performance whilst incorrect labels

can negatively affect model accuracy and reliability.

The collected datasets were imported into CVAT, which is an open-source image annotation

platform which is mostly used for computer vision applications. This resource was utilized due

to its efficient annotation tools alongside its compatibility with YOLO training formats and

support for object detection tasks. Bounding boxes were manually drawn around each target

object as shown in the figure, the appropriate class label was then assigned. Separate classes

were created for the eggs, nuts and bolts to enable multi class object detection during model

training.


Figure 5-2: Bounding Box Annotations used for Training

Images were annotated systematically to maintain consistency throughout the dataset and

labelling inconsistencies were investigated to ensure there was no incorrect assignment of the

object. Once the annotations were complete, they were exported as a YOLO1.1 file so it can

directly be used within the training pipeline. This organised annotation workflow improved

dataset quality and reduced the likelihood of training errors during model development, the

assignment of objects was as follows: (1) Egg (2) Nut (3) Bolt (4) Compass, these affected the

label annotations as shown in the figure below. This figure displays an egg annotation; in the

image there appears to be 5 eggs therefore there are 5 rows of coordinates showing the

bounding box location in the corresponding image file. This ensures that the model understands

which label corresponds to which object. It is also important to note that the txt file names

correspond exactly to the image files.


Figure 5-3: Txt File for Egg Detection (1)

Following the annotations of the dataset, it was partitioned into training and validation with

80% of the dataset used to train and 20% used to test the effectiveness of the model. This allows

for model development alongside performance evaluation.
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

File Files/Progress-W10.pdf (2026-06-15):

# WEEKLY PROGRESS REPORT


# Mechatronic System Design (MEC483) – Course Project

PROJECT / PHASE

## Smart Pick and Place Robot

DATE RANGE
14/4/2026 – 21/4/2026

TEAM MEMBERS
Maher Abo Abed (1087993) , Sabeeha Zainab Hasham (1089042), Basel Feras Ghunaim (1088912), Ahmad Nasser Alshehhi (1090882)

# HOW ARE WE DOING THIS WEEK?

TOP WINS | KEY BLOCKERS / RISKS | PROJECT HEALTH


Scope | Under Execution
Schedule | Potential Delays
Fabrication & Prototyping | Under Execution

OPEN ISSUES

## 3 Active

- Successfully built and tested and IK model using moveit and Rviz for visualizing
- Built, tested and successfully controlled a pneumatic suction system that is capable of relatively high pay loads
- Set up the Raspberry pi with the current yolov8 model, connected and set up the camera – the full system is almost in place
- Blocker: Continued printing issues – prototype and assembly can’t be made yet, causing significant delays

Project Schedule (Gantt) | Agile Gantt chart1.xlsx (https://studentsaduac-my.sharepoint.com/:x:/g/personal/1087993_students_adu_ac_ae/IQCVl5X-gnVOTbJbda9AOzVBAQxvkQVJ4Exoq-0edEJwLJE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)

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

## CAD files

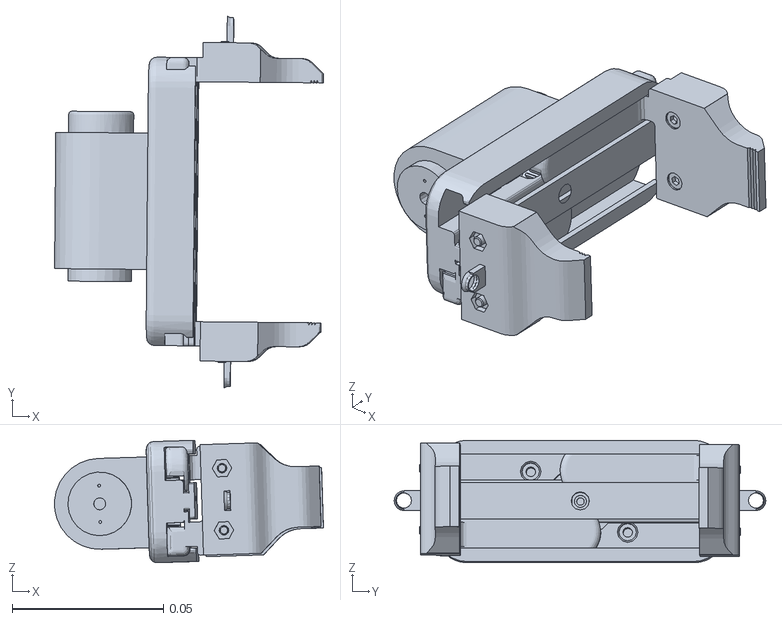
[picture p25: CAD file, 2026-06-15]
ROS/meshes/arm_link.STL
0.0888 x 0.123 x 0.0404

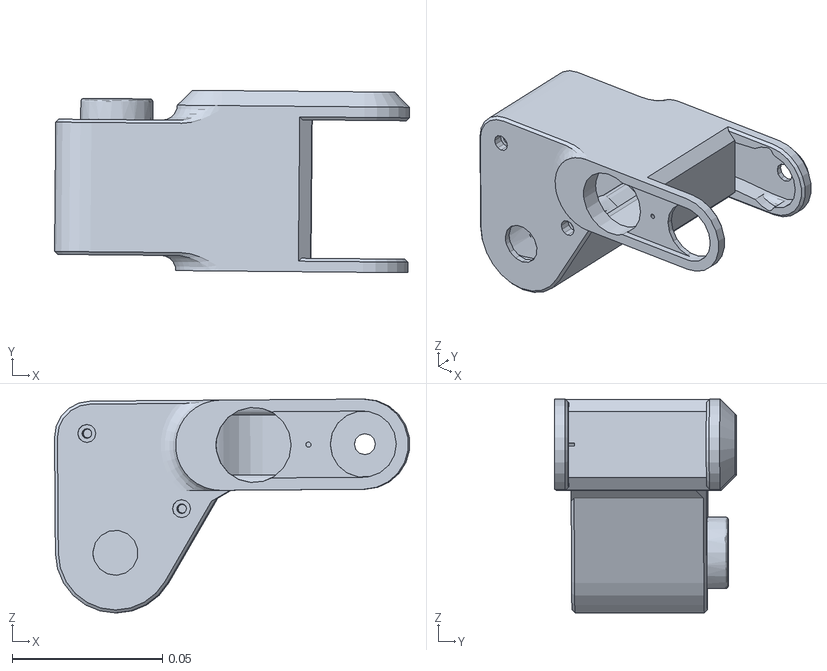
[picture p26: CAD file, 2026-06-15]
ROS/meshes/wrist_link.STL
0.118 x 0.0607 x 0.0711

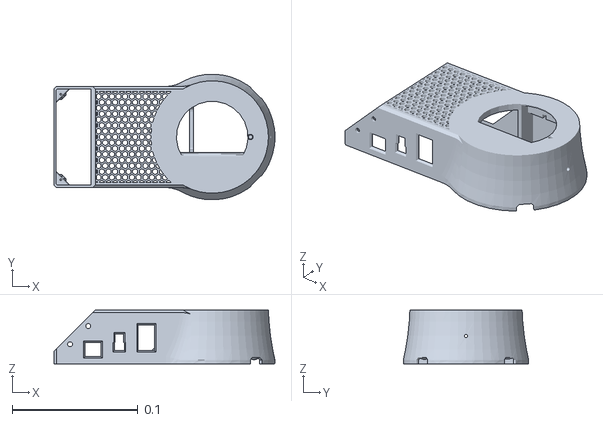
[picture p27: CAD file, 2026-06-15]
ROS/meshes/base_link.STL
0.176 x 0.0999 x 0.043

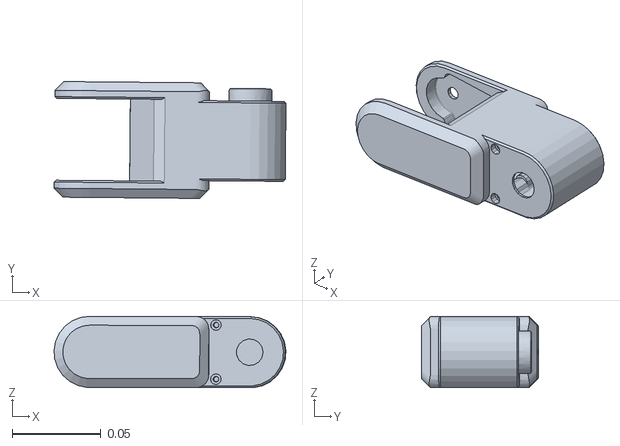
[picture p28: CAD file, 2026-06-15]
ROS/meshes/elbow_link.STL
0.13 x 0.0657 x 0.0401

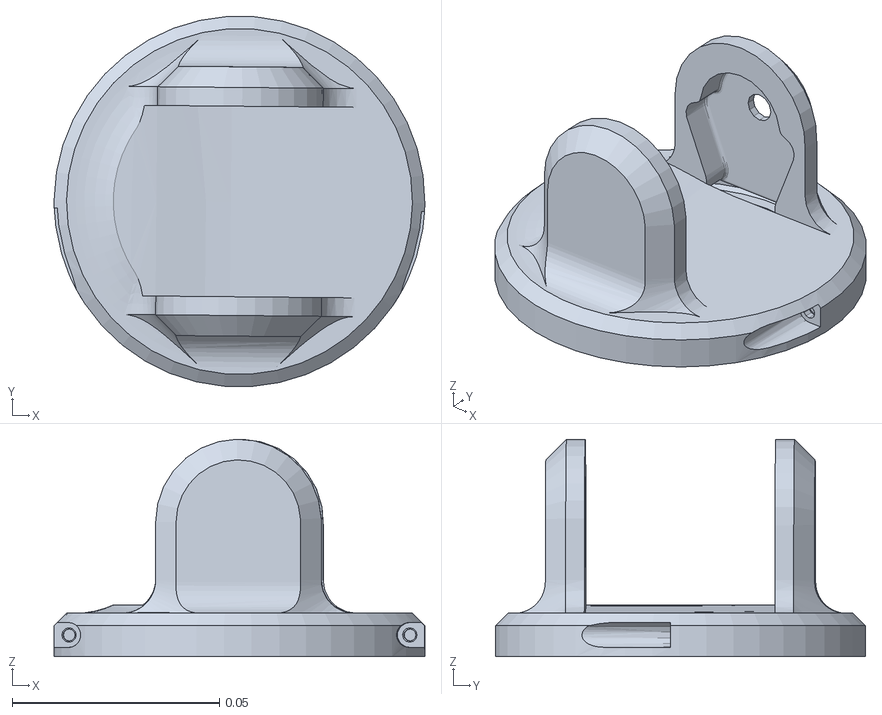
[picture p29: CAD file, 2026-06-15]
ROS/meshes/shoulder_link.STL
0.0895 x 0.0893 x 0.0525

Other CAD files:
ROS/meshes/end_link.STL

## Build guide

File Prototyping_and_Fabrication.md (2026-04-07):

## ● Manufacturing Process
The robot was designed with practicality in mind, so all parts could be made using tools readily available in the lab. Most of the structural components are currently being 3D printed using PLA on a Raise3D E2 printer, which makes it easy to prototype, test, and quickly update designs without adding much cost. This approach allows for fast iteration as improvements are made. In cases where more precision or strength is needed, processes like laser cutting. Wherever possible, off-the-shelf components are incorporated to simplify the build and keep everything affordable.

● 3D printing (PLA, Raise3D E2)

● Laser cutting

● Off-the-shelf components

[STL Files](STL.zip)

## ● Assembly
The system was designed to be modular and easy to put together. The 3D printed parts are assembled using standard fasteners to form the main structure, and components like motors and electronics are integrated in a way that keeps everything accessible. This makes the overall assembly process straightforward and also allows for quick adjustments, repairs, or upgrades as the project evolves.

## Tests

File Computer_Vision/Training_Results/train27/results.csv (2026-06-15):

epoch | time | train/box_loss | train/cls_loss | train/dfl_loss | metrics/precision(B) | metrics/recall(B) | metrics/mAP50(B) | metrics/mAP50-95(B) | val/box_loss | val/cls_loss | val/dfl_loss | lr/pg0 | lr/pg1 | lr/pg2
1 | 199.765 | 3.87265 | 4.60476 | 4.24952 | 0.0001 | 0.00327 | 5e-05 | 2e-05 | 4.51422 | 17.3368 | 4.16199 | 0.0003 | 0.0003 | 0.0003
2 | 390.014 | 3.59989 | 4.07954 | 4.04114 | 0.0001 | 0.00374 | 5e-05 | 2e-05 | 4.55493 | 16.6416 | 4.19811 | 0.000606436 | 0.000606436 | 0.000606436
3 | 579.456 | 3.36808 | 3.63084 | 3.64284 | 0.00013 | 0.00421 | 7e-05 | 3e-05 | 4.71859 | 16.1262 | 4.42059 | 0.000906685 | 0.000906685 | 0.000906685
4 | 768.47 | 3.13542 | 3.45388 | 3.32234 | 0.00012 | 0.00374 | 6e-05 | 2e-05 | 4.75814 | 14.3913 | 4.55358 | 0.00120075 | 0.00120075 | 0.00120075
5 | 958.07 | 3.06676 | 3.20605 | 3.12709 | 0.00025 | 0.00573 | 0.00015 | 4e-05 | 4.66161 | 12.3017 | 4.34026 | 0.0012005 | 0.0012005 | 0.0012005
6 | 1152.22 | 2.90376 | 3.03402 | 2.86496 | 0.08698 | 0.20487 | 0.05418 | 0.01861 | 2.83949 | 15.0809 | 2.97522 | 0.00118812 | 0.00118812 | 0.00118812
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

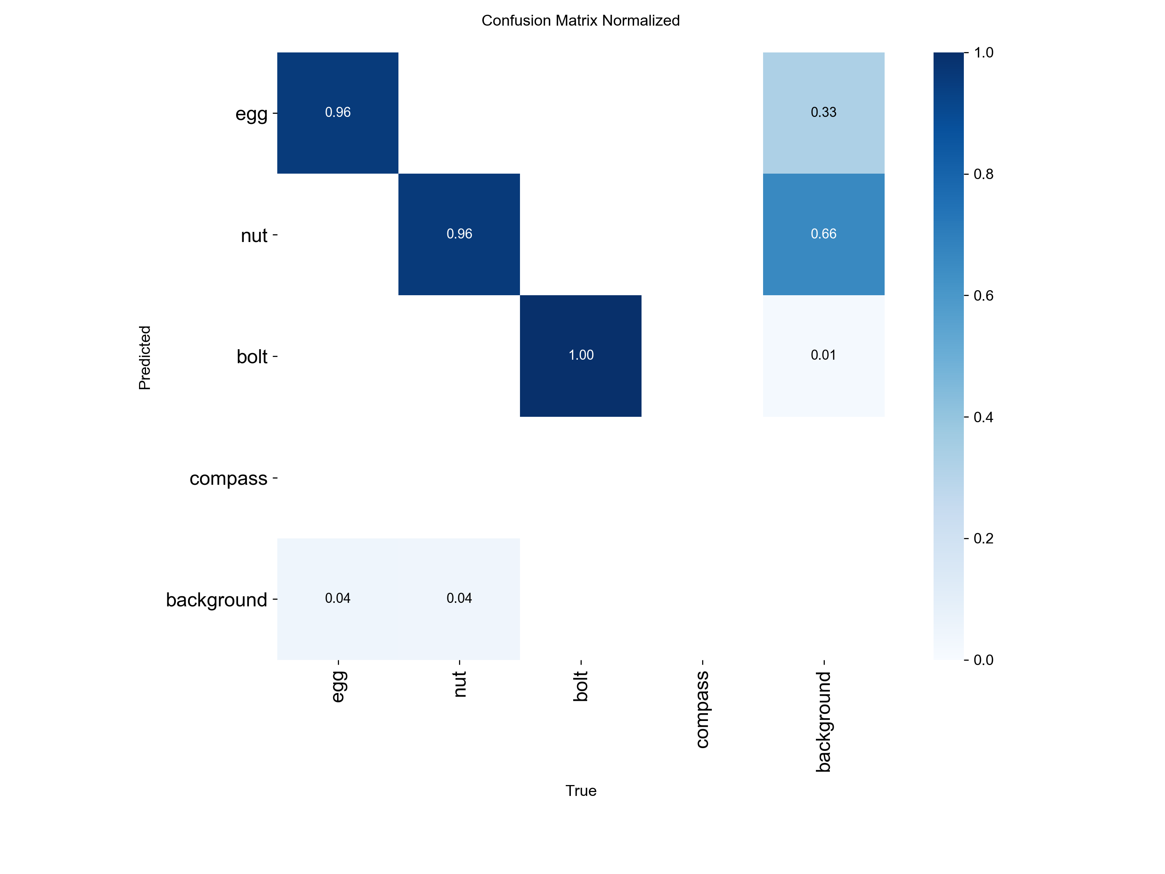
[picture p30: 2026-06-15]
Computer_Vision/Training_Results/train27/confusion_matrix_normalized.png

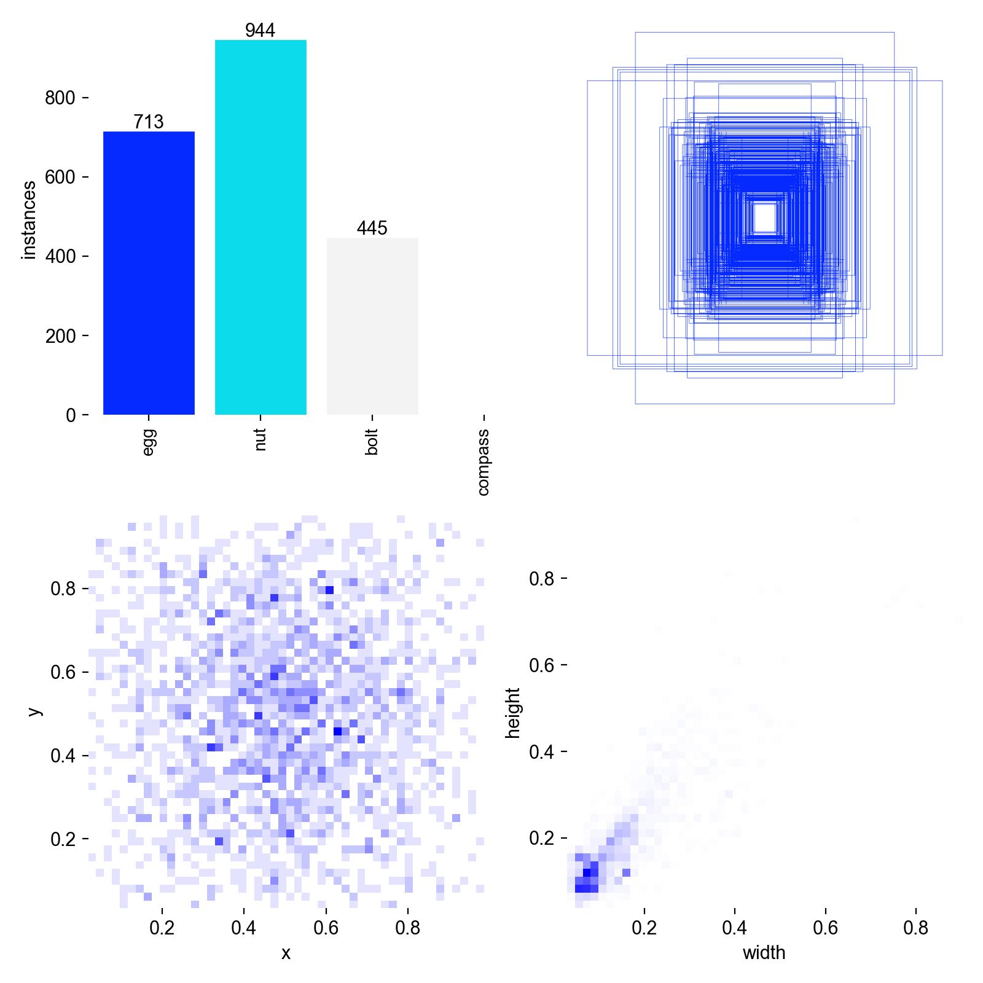
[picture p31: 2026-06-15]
Computer_Vision/Training_Results/train27/labels.jpg

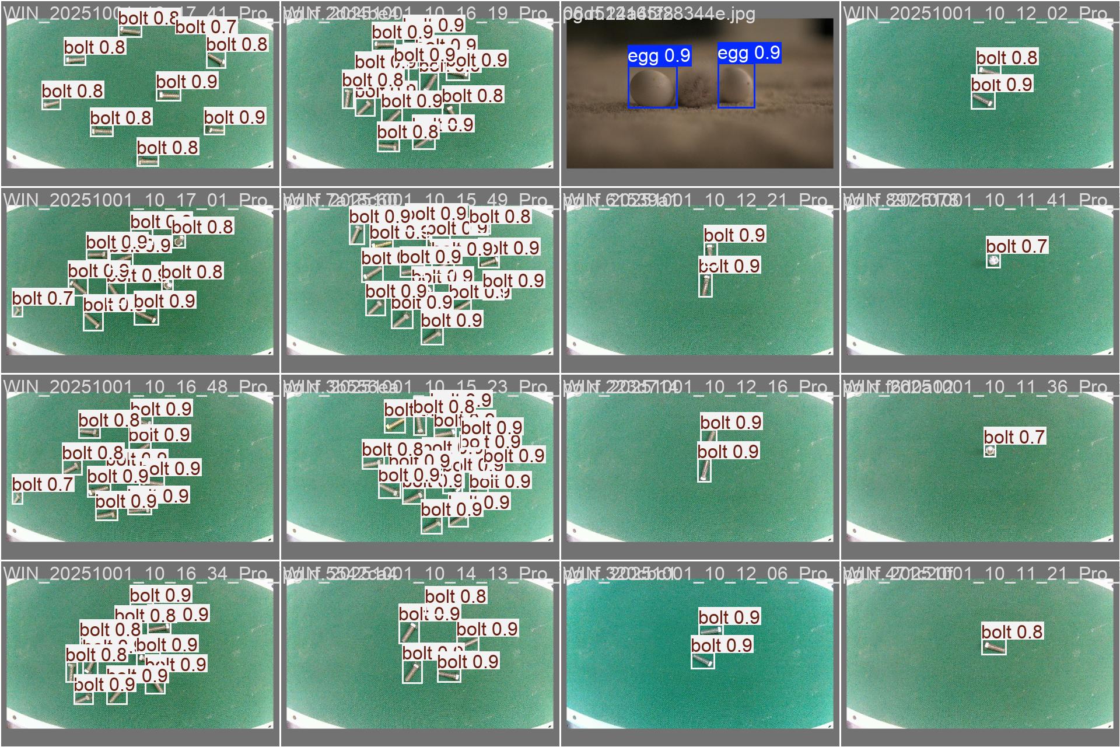
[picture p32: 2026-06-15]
Computer_Vision/Training_Results/train27/val_batch1_pred.jpg

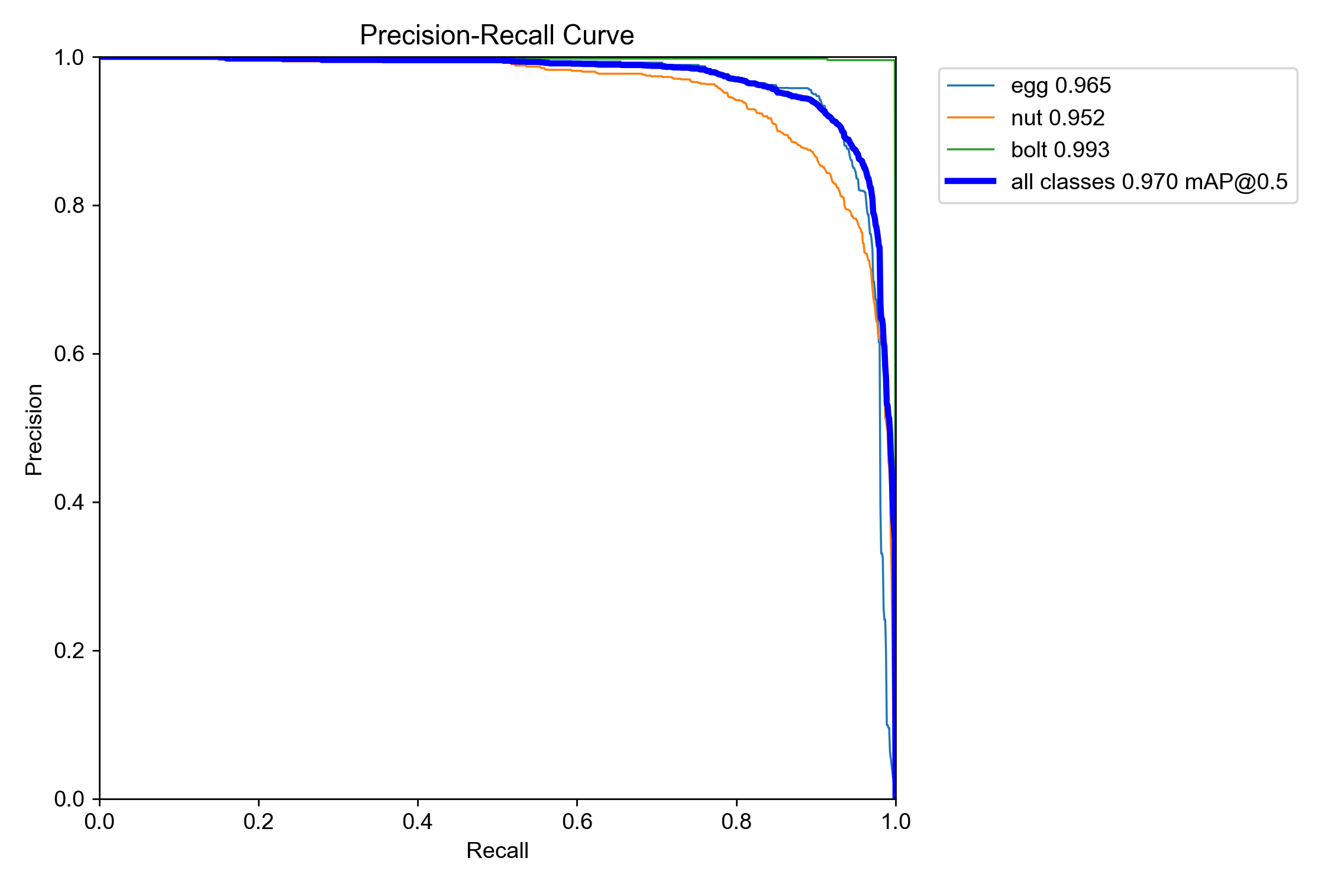
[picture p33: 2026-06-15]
Computer_Vision/Training_Results/train27/BoxPR_curve.png

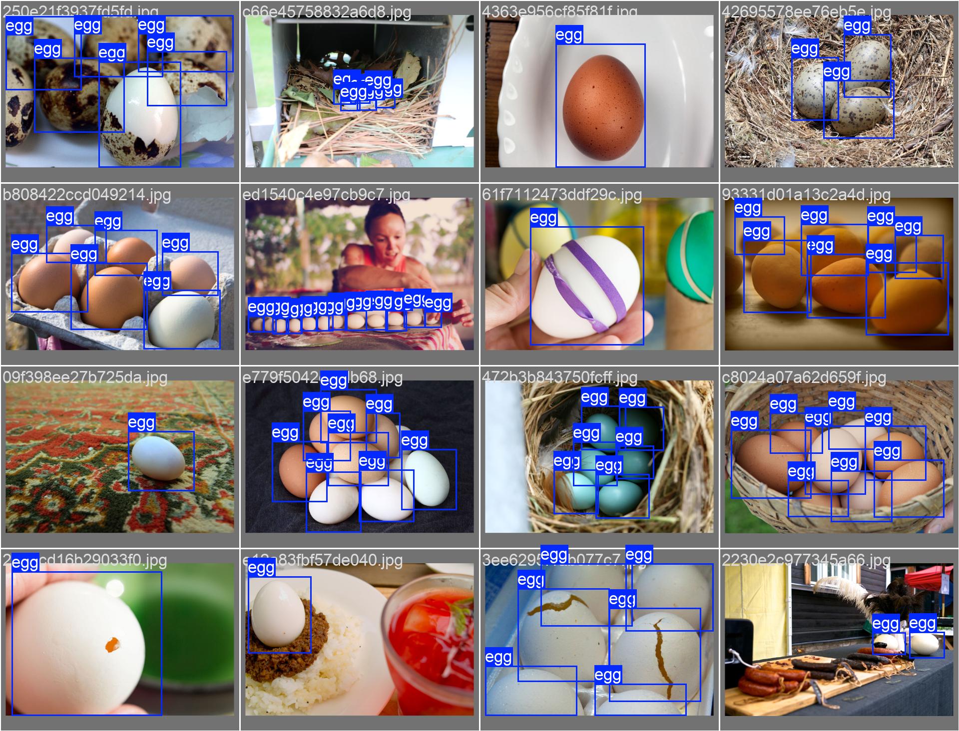
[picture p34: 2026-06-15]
Computer_Vision/Training_Results/train27/val_batch2_labels.jpg

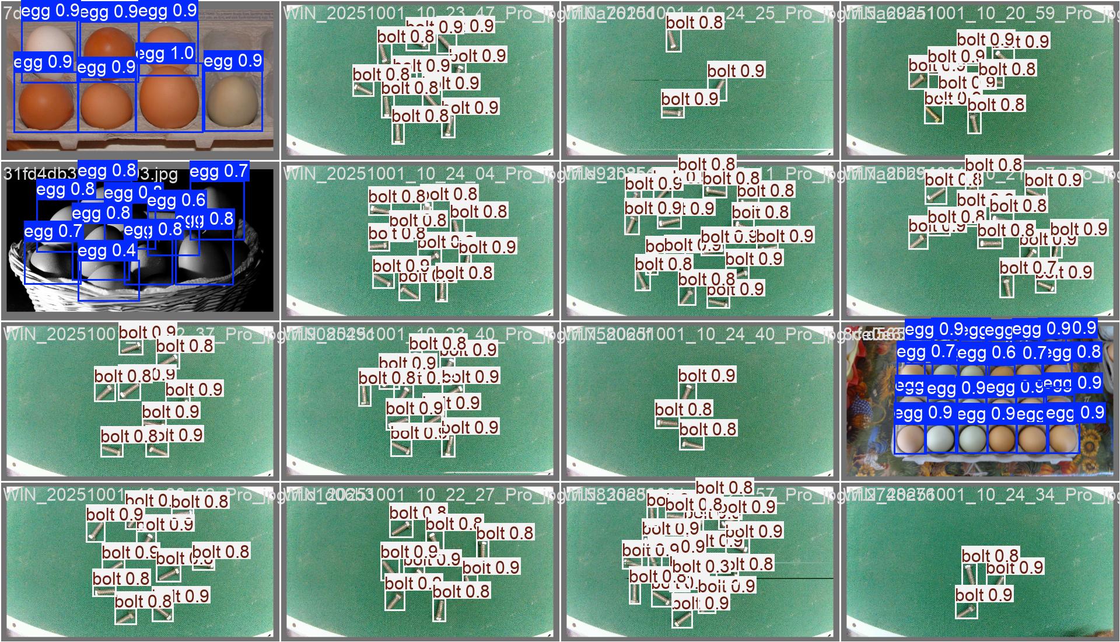
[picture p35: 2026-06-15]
Computer_Vision/Training_Results/train27/val_batch0_pred.jpg

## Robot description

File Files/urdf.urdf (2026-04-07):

<?xml version="1.0" encoding="utf-8"?>
<!-- This URDF was automatically created by SolidWorks to URDF Exporter! Originally created by Stephen Brawner (brawner@gmail.com) 
     Commit Version: 1.6.0-4-g7f85cfe  Build Version: 1.6.7995.38578
     For more information, please see http://wiki.ros.org/sw_urdf_exporter -->
<?xml version="1.0" encoding="utf-8"?>
<robot name="urdf">

  <link name="base_link">
    <inertial>
      <origin xyz="0.0010046 0.0010584 0.00107405" rpy="0 0 0"/>
      <mass value="0.207333995383758"/>
      <inertia ixx="0.000243532408154124" ixy="-8.71165917808198E-07" ixz="1.6651626169009E-05" iyy="0.000567529634612306" iyz="5.00374734708056E-06" izz="0.000401905114298968"/>
    </inertial>

    <visual>
      <origin xyz="0 0 0" rpy="0 0 0"/>
      <geometry>
        <mesh filename="package://urdf/meshes/base_link.STL" scale="0.001 0.001 0.001"/>
      </geometry>
    </visual>

    <collision>
      <origin xyz="0 0 0" rpy="0 0 0"/>
      <geometry>
        <mesh filename="package://urdf/meshes/base_link.STL" scale="0.001 0.001 0.001"/>
      </geometry>
    </collision>
  </link>

  <link name="shoulder_Link">
    <inertial>
      <origin xyz="6.39e-07 1.384e-05 -2.212e-06" rpy="0 0 0"/>
      <mass value="0.0563566428512413"/>
      <inertia ixx="1.62423302062928E-05" ixy="8.59445809560576E-08" ixz="-1.81851941552393E-07" iyy="3.08941911733891E-05" iyz="7.80567427296864E-08" izz="3.38539297343189E-05"/>
    </inertial>

    <visual>
      <geometry>
        <mesh filename="package://urdf/meshes/shoulder_Link.STL" scale="0.001 0.001 0.001"/>
      </geometry>
    </visual>

    <collision>
      <geometry>
        <mesh filename="package://urdf/meshes/shoulder_Link.STL" scale="0.001 0.001 0.001"/>
      </geometry>
    </collision>
  </link>

  <joint name="j1" type="revolute">
    <origin xyz="0.00099263 -0.001076 0.0010745" rpy="1.5708 0 0"/>
    <parent link="base_link"/>
    <child link="shoulder_Link"/>
    <axis xyz="0 1 0"/>
    <limit lower="-1.57" upper="1.57" effort="1" velocity="7"/>
  </joint>

  <link name="elbow_Link">
    <inertial>
      <origin xyz="-3.077e-05 3.175e-05 -4.747e-06" rpy="0 0 0"/>
      <mass value="0.0763033017252141"/>
      <inertia ixx="5.18279369702417E-05" ixy="3.26444616888044E-05" ixz="-1.8772014772101E-06" iyy="4.97144747382547E-05" iyz="1.82804815551204E-06" izz="9.04301240312875E-05"/>
    </inertial>

    <visual>
      <geometry>
        <mesh filename="package://urdf/meshes/elbow_Link.STL" scale="0.001 0.001 0.001"/>
      </geometry>
    </visual>

    <collision>
      <geometry>
        <mesh filename="package://urdf/meshes/elbow_Link.STL" scale="0.001 0.001 0.001"/>
      </geometry>
    </collision>
  </link>

  <joint name="j2" type="revolute">
    <origin xyz="0 0.0000325 0" rpy="0.0065862 0.01558 -2.3417"/>
    <parent link="shoulder_Link"/>
    <child link="elbow_Link"/>
    <axis xyz="0.0091818 0 -0.99996"/>
    <limit lower="-1.57" upper="1.57" effort="1" velocity="7"/>
  </joint>

  <link name="wrist_Link">
    <inertial>
      <origin xyz="-3.394e-05 1.366e-06 1.070e-06" rpy="0 0 0"/>
      <mass value="0.0654092355161869"/>
      <inertia ixx="3.40346445188127E-05" ixy="-1.60991148226838E-05" ixz="3.88687642355712E-07" iyy="5.74604621239122E-05" iyz="6.71998562090846E-07" izz="8.30175162306963E-05"/>
    </inertial>

    <visual>
      <geometry>
        <mesh filename="package://urdf/meshes/wrist_Link.STL" scale="0.001 0.001 0.001"/>
      </geometry>
    </visual>

    <collision>
      <geometry>
        <mesh filename="package://urdf/meshes/wrist_Link.STL" scale="0.001 0.001 0.001"/>
      </geometry>
    </collision>
  </link>

  <joint name="j3" type="revolute">
    <origin xyz="-0.000063182 0.000064091 -5.8015e-07" rpy="-0.0091725 0.0087575 1.5245"/>
    <parent link="elbow_Link"/>
    <child link="wrist_Link"/>
    <axis xyz="0.0091818 0 -0.99996"/>
    <limit lower="-1.57" upper="1.57" effort="1" velocity="7"/>
  </joint>

  <link name="gripper_Link">
    <inertial>
      <origin xyz="0.0008589 0.00116735 0.00099513" rpy="0 0 0"/>
      <mass value="0.098263192134599"/>
      <inertia ixx="3.46471414908844E-05" ixy="1.00912869162929E-06" ixz="6.3186394043883E-06" iyy="3.29486848268827E-05" iyz="9.22781542077519E-08" izz="1.3092056266252E-05"/>
    </inertial>

    <visual>
      <geometry>
        <mesh filename="package://urdf/meshes/gripper_Link.STL" scale="0.001 0.001 0.001"/>
      </geometry>
    </visual>

    <collision>
      <geometry>
        <mesh filename="package://urdf/meshes/gripper_Link.STL" scale="0.001 0.001 0.001"/>
      </geometry>
    </collision>
  </link>

  <joint name="j4" type="revolute">
    <origin xyz="-0.0004209 -0.0016209 -0.00071005" rpy="-0.0050088 0.28768 0.54904"/>
    <parent link="wrist_Link"/>
    <child link="gripper_Link"/>
    <axis xyz="0 0 0"/>
  </joint>

</robot>

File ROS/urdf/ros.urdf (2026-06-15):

<?xml version="1.0" encoding="utf-8"?>
<!-- This URDF was automatically created by SolidWorks to URDF Exporter! Originally created by Stephen Brawner (brawner@gmail.com) 
     Commit Version: 1.6.0-4-g7f85cfe  Build Version: 1.6.7995.38578
     For more information, please see http://wiki.ros.org/sw_urdf_exporter -->
<robot name="ros">
  <link name="base_link">
    <inertial>
      <origin xyz="-0.0119706314721355 -0.00191511867991667 0.0269109810347072" rpy="0 0 0" />
      <mass value="0.207333995156467" />
      <inertia ixx="0.000243532408098101" ixy="-1.66516260572353E-05" ixz="8.71165793342081E-07" iyy="0.000401905113848341" iyz="5.00374730366925E-06" izz="0.00056752963416904" />
    </inertial>
    <visual>
      <origin xyz="0 0 0" rpy="0 0 0" />
      <geometry>
        <mesh filename="package://ros/meshes/base_link.STL" />
      </geometry>
      <material name="">
        <color rgba="0.698039215686274 0.698039215686274 0.698039215686274 1" />
      </material>
    </visual>
    <collision>
      <origin xyz="0 0 0" rpy="0 0 0" />
      <geometry>
        <mesh filename="package://ros/meshes/base_link.STL" />
      </geometry>
    </collision>
  </link>
  <link name="shoulder_link">
    <inertial>
      <origin xyz="-0.000639020221566255 -0.00221268013319542 0.0138447847140262" rpy="0 0 0" />
      <mass value="0.0563566428512417" />
      <inertia ixx="1.62423302062928E-05" ixy="1.81851941552224E-07" ixz="-8.59445809561107E-08" iyy="3.38539297343194E-05" iyz="7.80567427296733E-08" izz="3.08941911733896E-05" />
    </inertial>
    <visual>
      <origin xyz="0 0 0" rpy="0 0 0" />
      <geometry>
        <mesh filename="package://ros/meshes/shoulder_link.STL" />
      </geometry>
      <material name="">
        <color rgba="0.698039215686274 0.698039215686274 0.698039215686274 1" />
      </material>
    </visual>
    <collision>
      <origin xyz="0 0 0" rpy="0 0 0" />
      <geometry>
        <mesh filename="package://ros/meshes/shoulder_link.STL" />
      </geometry>
    </collision>
  </link>
  <joint name="shoulder" type="revolute">
    <origin xyz="0 0 0.043" rpy="0 0 0" />
    <parent link="base_link" />
    <child link="shoulder_link" />
    <axis xyz="0 0 -1" />
    <limit lower="-1.57" upper="1.57" effort="7" velocity="100" />
  </joint>
  <link name="elbow_link">
    <inertial>
      <origin xyz="-0.0445855896233995 -0.0365571155750264 -0.000253561026126059" rpy="0 0 0" />
      <mass value="0.0763033017187473" />
      <inertia ixx="1.80485917861405E-05" ixy="-1.49220878107006E-06" ixz="-4.39899920280866E-07" iyy="9.04948491469838E-05" iyz="1.98022509869592E-08" izz="8.34290948055152E-05" />
    </inertial>
    <visual>
      <origin xyz="0 0 0" rpy="0 0 0" />
      <geometry>
        <mesh filename="package://ros/meshes/elbow_link.STL" />
      </geometry>
      <material name="">
        <color rgba="0.698039215686274 0.698039215686274 0.698039215686274 1" />
      </material>
    </visual>
    <collision>
      <origin xyz="0 0 0" rpy="0 0 0" />
      <geometry>
        <mesh filename="package://ros/meshes/elbow_link.STL" />
      </geometry>
    </collision>
  </link>
  <joint name="elbow" type="revolute">
    <origin xyz="0.00030753 0.032499 0.0325" rpy="0 0 0" />
    <parent link="shoulder_link" />
    <child link="elbow_link" />
    <axis xyz="0.0091818 0.99996 0" />
    <limit lower="-1.57" upper="1.57" effort="7" velocity="100" />
  </joint>
  <link name="wrist_link">
    <inertial>
      <origin xyz="0.0217856217876145 -0.0318188170084459 0.026638033909097" rpy="0 0 0" />
      <mass value="0.0654092355348391" />
      <inertia ixx="3.05616966043891E-05" ixy="-6.89622438236125E-07" ixz="-1.28747139515531E-05" iyy="8.30233360121273E-05" iyz="6.13486908938219E-08" izz="6.092759122282E-05" />
    </inertial>
    <visual>
      <origin xyz="0 0 0" rpy="0 0 0" />
      <geometry>
        <mesh filename="package://ros/meshes/wrist_link.STL" />
      </geometry>
      <material name="">
        <color rgba="0.698039215686274 0.698039215686274 0.698039215686274 1" />
      </material>
    </visual>
    <collision>
      <origin xyz="0 0 0" rpy="0 0 0" />
      <geometry>
        <mesh filename="package://ros/meshes/wrist_link.STL" />
      </geometry>
    </collision>
  </link>
  <joint name="wrist" type="revolute">
    <origin xyz="-0.089989 0.0013263 -0.00065113" rpy="0 0 0" />
    <parent link="elbow_link" />
    <child link="wrist_link" />
    <axis xyz="0.0091818 0.99996 0" />
    <limit lower="-1.57" upper="1.57" effort="7" velocity="100" />
  </joint>
  <link name="arm_link">
    <inertial>
      <origin xyz="0.0239722994937728 -0.03302776033887 0.000872939224965563" rpy="0 0 0" />
      <mass value="0.0937307858723876" />
      <inertia ixx="4.68784104332079E-05" ixy="-7.6546734565155E-07" ixz="1.53121871245673E-07" iyy="1.45097565093586E-05" iyz="1.05512529017752E-06" izz="4.22627250595636E-05" />
    </inertial>
    <visual>
      <origin xyz="0 0 0" rpy="0 0 0" />
      <geometry>
        <mesh filename="package://ros/meshes/arm_link.STL" />
      </geometry>
      <material name="">
        <color rgba="0.76078431372549 0.807843137254902 0.83921568627451 1" />
      </material>
    </visual>
    <collision>
      <origin xyz="0 0 0" rpy="0 0 0" />
      <geometry>
        <mesh filename="package://ros/meshes/arm_link.STL" />
      </geometry>
    </collision>
  </link>
  <joint name="arm" type="revolute">
    <origin xyz="0.082112 -0.001254 0.036827" rpy="0 0 0" />
    <parent link="wrist_link" />
    <child link="arm_link" />
    <axis xyz="0.0091818 0.99996 0" />
    <limit lower="-1.57" upper="1.57" effort="7" velocity="100" />
  </joint>
  <link name="end_link">
    <inertial>
      <origin xyz="-0.03151634044226 0.000262876989696625 -0.000233659250883145" rpy="0 0 0" />
      <mass value="0.0937307858723876" />
      <inertia ixx="4.68784104332079E-05" ixy="-7.65467345651551E-07" ixz="1.53121871245673E-07" iyy="1.45097565093586E-05" iyz="1.05512529017752E-06" izz="4.22627250595636E-05" />
    </inertial>
    <visual>
      <origin xyz="0 0 0" rpy="0 0 0" />
      <geometry>
        <mesh filename="package://ros/meshes/end_link.STL" />
      </geometry>
      <material name="">
        <color rgba="0.76078431372549 0.807843137254902 0.83921568627451 1" />
      </material>
    </visual>
    <collision>
      <origin xyz="0 0 0" rpy="0 0 0" />
      <geometry>
        <mesh filename="package://ros/meshes/end_link.STL" />
      </geometry>
    </collision>
  </link>
  <joint name="end" type="fixed">
    <origin xyz="0.055489 -0.033291 0.0011066" rpy="0 0 0" />
    <parent link="arm_link" />
    <child link="end_link" />
    <axis xyz="0 0 0" />
  </joint>
</robot>

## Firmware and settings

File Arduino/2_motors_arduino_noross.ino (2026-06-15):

#include <Wire.h>
#include <Adafruit_PWMServoDriver.h>
#include <SoftwareSerial.h>
#include <string.h>

Adafruit_PWMServoDriver pwm = Adafruit_PWMServoDriver(0x40);

// HC-05 Bluetooth
// HC-05 TXD -> Arduino D2
// HC-05 RXD -> Arduino D3
SoftwareSerial bluetooth(2, 3);

// PCA9685 channels
const byte ELBOW_CHANNEL = 3;
const byte WRIST_CHANNEL = 4;
const byte GRIPPER_CHANNEL = 15;

const int SERVO_FREQ = 50;

// Pump relay. D10 is the same signal wire previously used for the MOSFET.
const byte PUMP_PIN = 10;
const byte PUMP_RELAY_ON_LEVEL = HIGH;
const byte PUMP_RELAY_OFF_LEVEL = LOW;

// L298N platform pins
const byte MOTOR_A_IN1 = 6;
const byte MOTOR_A_IN2 = 7;
const byte MOTOR_B_IN1 = 8;
const byte MOTOR_B_IN2 = 9;
const byte MOTOR_A_EN  = 11;  // PWM
const byte MOTOR_B_EN  = 12;  // Not PWM on Uno, used ON/OFF

// Servo calibration
const int ELBOW_MIN_PULSE = 120;
const int ELBOW_MAX_PULSE = 600;

const int WRIST_MIN_TICKS = 400;
const int WRIST_MAX_TICKS = 600;

const int GRIPPER_MIN_PULSE = 150;
const int GRIPPER_MAX_PULSE = 550;

// Platform speeds
int platformLeftSpeed = 180;
int platformRightSpeed = 180;

// Servo smoothing. Smaller step and larger delay make motion softer but slower.
const int SERVO_SMOOTH_STEP = 2;
const int SERVO_SMOOTH_DELAY_MS = 12;
int currentElbowPulse = -1;
int currentWristTicks = -1;
int currentGripperPulse = -1;

bool emergencyActive = false;
bool pumpPulseActive = false;
unsigned long pumpPulseEndTime = 0;

// Calibrated physical home: elbow appears 90 deg, wrist appears 0 deg.
const int HOME_ELBOW_ANGLE = 55;
const int HOME_WRIST_ANGLE = 0;
const int HOME_GRIPPER_ANGLE = 90;

// Serial input buffers
char usbBuffer[50];
char btBuffer[50];
byte usbIndex = 0;
byte btIndex = 0;

// =============================
// Helpers
// =============================

void sendReply(const __FlashStringHelper *message) {
  Serial.println(message);
  bluetooth.println(message);
}

void sendReplyText(const char *message) {
  Serial.println(message);
  bluetooth.println(message);
}

int getValueAfterColon(char *command) {
  char *colon = strchr(command, ':');

  if (colon == NULL) {
    return 90;
  }

  return atoi(colon + 1);
}

char* getTextAfterColon(char *command) {
  char *colon = strchr(command, ':');

  if (colon == NULL) {
    return command;
  }

  return colon + 1;
}

bool commandStartsWith(char *command, const char *prefix) {
  return strncmp(command, prefix, strlen(prefix)) == 0;
}

int speedTextToPWM(char *speedText) {
  if (strcmp(speedText, "SLOW") == 0) return 120;
  if (strcmp(speedText, "MEDIUM") == 0) return 180;
  if (strcmp(speedText, "FAST") == 0) return 240;

  return 180;
}

// =============================
// Servo Mapping
// =============================

int elbowAngleToPulse(int angle) {
  angle = constrain(angle, 0, 180);
  return map(angle, 0, 180, ELBOW_MIN_PULSE, ELBOW_MAX_PULSE);
}

int wristAngleToTicks(int angle) {
  angle = constrain(angle, 0, 180);
  return map(angle, 0, 180, WRIST_MIN_TICKS, WRIST_MAX_TICKS);
}

int gripperAngleToPulse(int angle) {
  angle = constrain(angle, 0, 180);
  return map(angle, 0, 180, GRIPPER_MIN_PULSE, GRIPPER_MAX_PULSE);
}

// =============================
// Arm Control
// =============================

void stopAllOutputs();

void smoothPwmMove(byte channel, int &currentValue, int targetValue) {
  if (currentValue < 0) {
    currentValue = targetValue;
    pwm.setPWM(channel, 0, targetValue);
    return;
  }

  while (currentValue != targetValue) {
    if (emergencyActive) {
      stopAllOutputs();
      return;
    }

    int delta = targetValue - currentValue;
    if (abs(delta) <= SERVO_SMOOTH_STEP) {
      currentValue = targetValue;
    } else {
      currentValue += delta > 0 ? SERVO_SMOOTH_STEP : -SERVO_SMOOTH_STEP;
    }

    pwm.setPWM(channel, 0, currentValue);
    delay(SERVO_SMOOTH_DELAY_MS);
  }
}

void moveElbow(int angle) {
  angle = constrain(angle, 0, 180);
  int pulse = elbowAngleToPulse(angle);

  smoothPwmMove(ELBOW_CHANNEL, currentElbowPulse, pulse);

  Serial.print(F("OK ELBOW_JOINT "));
  Serial.print(angle);
  Serial.print(F(" PULSE "));
  Serial.println(pulse);

  bluetooth.print(F("OK ELBOW_JOINT "));
  bluetooth.print(angle);
  bluetooth.print(F(" PULSE "));
  bluetooth.println(pulse);
}

void moveWrist(int angle) {
  angle = constrain(angle, 0, 180);
  int ticks = wristAngleToTicks(angle);

  smoothPwmMove(WRIST_CHANNEL, currentWristTicks, ticks);

  Serial.print(F("OK WRIST_JOINT "));
  Serial.print(angle);
  Serial.print(F(" TICKS "));
  Serial.println(ticks);

  bluetooth.print(F("OK WRIST_JOINT "));
  bluetooth.print(angle);
  bluetooth.print(F(" TICKS "));
  bluetooth.println(ticks);
}

void moveGripper(int angle) {
  angle = constrain(angle, 0, 180);
  int pulse = gripperAngleToPulse(angle);

  smoothPwmMove(GRIPPER_CHANNEL, currentGripperPulse, pulse);

  Serial.print(F("OK NORMAL_GRIPPER_ANGLE "));
  Serial.print(angle);
  Serial.print(F(" PULSE "));
  Serial.println(pulse);

  bluetooth.print(F("OK NORMAL_GRIPPER_ANGLE "));
  bluetooth.print(angle);
  bluetooth.print(F(" PULSE "));
  bluetooth.println(pulse);
}

// =============================
// Pump Control
// =============================

void pumpOn() {
  pumpPulseActive = false;
  digitalWrite(PUMP_PIN, PUMP_RELAY_ON_LEVEL);
  sendReply(F("OK SUCTION_CUP_ON"));
}

void pumpOff() {
  pumpPulseActive = false;
  digitalWrite(PUMP_PIN, PUMP_RELAY_OFF_LEVEL);
  sendReply(F("OK SUCTION_CUP_OFF"));
}

void pumpPulse() {
  // Non-blocking pulse keeps USB/Bluetooth command handling responsive to EMERGENCY_STOP.
  sendReply(F("OK SUCTION_CUP_PULSE START"));
  pumpPulseActive = true;
  pumpPulseEndTime = millis() + 2000UL;
  digitalWrite(PUMP_PIN, PUMP_RELAY_ON_LEVEL);
}

void servicePumpPulse() {
  if (!pumpPulseActive) return;
  if ((long)(millis() - pumpPulseEndTime) < 0) return;

  pumpPulseActive = false;
  digitalWrite(PUMP_PIN, PUMP_RELAY_OFF_LEVEL);
  sendReply(F("OK SUCTION_CUP_PULSE COMPLETE"));
}

// =============================
// Platform Motor Control
// =============================

void setMotorA(int direction, int speedPWM) {
  if (direction > 0) {
    digitalWrite(MOTOR_A_IN1, HIGH);
    digitalWrite(MOTOR_A_IN2, LOW);
  } 
  else if (direction < 0) {
    digitalWrite(MOTOR_A_IN1, LOW);
    digitalWrite(MOTOR_A_IN2, HIGH);
  } 
  else {
    digitalWrite(MOTOR_A_IN1, LOW);
    digitalWrite(MOTOR_A_IN2, LOW);
  }

  analogWrite(MOTOR_A_EN, speedPWM);
}

void setMotorB(int direction, int speedPWM) {
  if (direction > 0) {
    digitalWrite(MOTOR_B_IN1, HIGH);
    digitalWrite(MOTOR_B_IN2, LOW);
  } 
  else if (direction < 0) {
    digitalWrite(MOTOR_B_IN1, LOW);
    digitalWrite(MOTOR_B_IN2, HIGH);
  } 
  else {
    digitalWrite(MOTOR_B_IN1, LOW);
    digitalWrite(MOTOR_B_IN2, LOW);
  }

  // D12 is not PWM on Uno, so Motor B enable is ON/OFF.
  digitalWrite(MOTOR_B_EN, speedPWM > 0 ? HIGH : LOW);
}

void movePlatform(int leftDirection, int rightDirection) {
  // With motor + wires on OUT1/OUT3 and - wires on OUT2/OUT4, 1 means IN1/IN3 HIGH.
  // If one side drives backward, change only that side's sign to -1.
  const int LEFT_MOTOR_DIRECTION_SIGN = 1;
  const int RIGHT_MOTOR_DIRECTION_SIGN = 1;

  setMotorA(leftDirection * LEFT_MOTOR_DIRECTION_SIGN, platformLeftSpeed);
  setMotorB(rightDirection * RIGHT_MOTOR_DIRECTION_SIGN, platformRightSpeed);
}

void stopPlatform() {
  setMotorA(0, 0);
  setMotorB(0, 0);
}

void runPlatformMotorTest() {
  // Short diagnostic pulses help verify L298N wiring without latching motion.
  sendReply(F("OK PLATFORM_MOTOR_TEST MOTOR_A"));
  setMotorA(1, 220);
  setMotorB(0, 0);
  delay(650);
  stopPlatform();
  delay(250);

  sendReply(F("OK PLATFORM_MOTOR_TEST MOTOR_B"));
  setMotorA(0, 0);
  setMotorB(1, 220);
  delay(650);
  stopPlatform();
  sendReply(F("OK PLATFORM_MOTOR_TEST COMPLETE"));
}

// =============================
// Safety / Home
// =============================

void stopAllOutputs() {
  pumpPulseActive = false;
  pwm.setPWM(ELBOW_CHANNEL, 0, 0);
  pwm.setPWM(WRIST_CHANNEL, 0, 0);
  pwm.setPWM(GRIPPER_CHANNEL, 0, 0);
  currentElbowPulse = -1;
  currentWristTicks = -1;
  currentGripperPulse = -1;

  stopPlatform();

  digitalWrite(PUMP_PIN, PUMP_RELAY_OFF_LEVEL);

  sendReply(F("OK ALL_OUTPUTS_STOPPED"));
}

void runHomeSequence() {
  sendReply(F("OK HOME START"));

  moveElbow(HOME_ELBOW_ANGLE);
  delay(700);

  moveWrist(HOME_WRIST_ANGLE);
  delay(700);

  moveGripper(HOME_GRIPPER_ANGLE);
  delay(500);

  sendReply(F("OK HOME COMPLETE"));
}

// =============================
// Command Handler
// =============================

void handleCommand(char *command, const char *source) {
  if (command[0] == '\0') return;

  Serial.print(F("Received from "));
  Serial.print(source);
  Serial.print(F(": "));
  Serial.println(command);

  if (strcmp(command, "EMERGENCY_STOP") == 0) {
    emergencyActive = true;
    stopAllOutputs();
    sendReply(F("OK EMERGENCY_STOP"));
    return;
  }

  if (strcmp(command, "RESET_EMERGENCY") == 0) {
    emergencyActive = false;
    sendReply(F("OK RESET_EMERGENCY"));
    return;
  }

  if (emergencyActive) {
    sendReply(F("ERROR EMERGENCY_ACTIVE"));
    return;
  }

  if (strcmp(command, "HOME") == 0) {
    runHomeSequence();
    return;
  }

  if (strcmp(command, "GRIPPING_TOOL:NORMAL_GRIPPER") == 0) {
    pumpOff();
    sendReply(F("OK GRIPPING_TOOL NORMAL_GRIPPER"));
    return;
  }

  if (strcmp(command, "GRIPPING_TOOL:PNEUMATIC_SUCTION_CUP") == 0) {
    sendReply(F("OK GRIPPING_TOOL PNEUMATIC_SUCTION_CUP"));
    return;
  }

  if (commandStartsWith(command, "ELBOW_JOINT:")) {
    moveElbow(getValueAfterColon(command));
    return;
  }

  if (commandStartsWith(command, "WRIST_JOINT:")) {
    moveWrist(getValueAfterColon(command));
    return;
  }

  if (commandStartsWith(command, "NORMAL_GRIPPER_ANGLE:")) {
    moveGripper(getValueAfterColon(command));
    return;
  }

  if (strcmp(command, "SUCTION_CUP_ON") == 0) {
    pumpOn();
    return;
  }

  if (strcmp(command, "SUCTION_CUP_OFF") == 0) {
    pumpOff();
    return;
  }

  if (strcmp(command, "SUCTION_CUP_PULSE") == 0) {
    pumpPulse();
    return;
  }

  if (strcmp(command, "PLATFORM_FORWARD") == 0) {
    movePlatform(1, 1);
    sendReply(F("OK PLATFORM_FORWARD"));
    return;
  }

  if (strcmp(command, "PLATFORM_BACKWARD") == 0) {
    movePlatform(-1, -1);
    sendReply(F("OK PLATFORM_BACKWARD"));
    return;
  }

  if (strcmp(command, "PLATFORM_LEFT") == 0) {
    movePlatform(-1, 1);
    sendReply(F("OK PLATFORM_LEFT"));
    return;
  }

  if (strcmp(command, "PLATFORM_RIGHT") == 0) {
    movePlatform(1, -1);
    sendReply(F("OK PLATFORM_RIGHT"));
    return;
  }

  if (strcmp(command, "PLATFORM_STOP") == 0) {
    stopPlatform();
    sendReply(F("OK PLATFORM_STOP"));
    return;
  }

  if (strcmp(command, "PLATFORM_MOTOR_TEST") == 0) {
    runPlatformMotorTest();
    return;
  }

  if (strcmp(command, "PLATFORM_FORWARD_RIGHT") == 0) {
    movePlatform(1, 0);
    sendReply(F("OK PLATFORM_FORWARD_RIGHT"));
    return;
  }

  if (strcmp(command, "PLATFORM_FORWARD_LEFT") == 0) {
    movePlatform(0, 1);
    sendReply(F("OK PLATFORM_FORWARD_LEFT"));
    return;
  }

  if (strcmp(command, "PLATFORM_BACKWARD_RIGHT") == 0) {
    movePlatform(-1, 0);
    sendReply(F("OK PLATFORM_BACKWARD_RIGHT"));
    return;
  }

  if (strcmp(command, "PLATFORM_BACKWARD_LEFT") == 0) {
    movePlatform(0, -1);
    sendReply(F("OK PLATFORM_BACKWARD_LEFT"));
    return;
  }

  if (commandStartsWith(command, "PLATFORM_LEFT_MOTOR_SPEED:")) {
    char *speedText = getTextAfterColon(command);
    platformLeftSpeed = speedTextToPWM(speedText);
    sendReply(F("OK PLATFORM_LEFT_MOTOR_SPEED"));
    return;
  }

  if (commandStartsWith(command, "PLATFORM_RIGHT_MOTOR_SPEED:")) {
    char *speedText = getTextAfterColon(command);
    platformRightSpeed = speedTextToPWM(speedText);
    sendReply(F("OK PLATFORM_RIGHT_MOTOR_SPEED"));
    return;
  }

  if (commandStartsWith(command, "PLATFORM_BOTH_MOTORS_SPEED:")) {
    char *speedText = getTextAfterColon(command);
    int pwmValue = speedTextToPWM(speedText);
    platformLeftSpeed = pwmValue;
    platformRightSpeed = pwmValue;
    sendReply(F("OK PLATFORM_BOTH_MOTORS_SPEED"));
    return;
  }

  // Backward compatibility with old website command names
  if (commandStartsWith(command, "PLATFORM_MOTOR_1_SPEED:")) {
    char *speedText = getTextAfterColon(command);
    platformLeftSpeed = speedTextToPWM(speedText);
    sendReply(F("OK PLATFORM_MOTOR_1_SPEED_AS_LEFT"));
    return;
  }

  if (commandStartsWith(command, "PLATFORM_MOTOR_2_SPEED:")) {
    char *speedText = getTextAfterColon(command);
    platformRightSpeed = speedTextToPWM(speedText);
    sendReply(F("OK PLATFORM_MOTOR_2_SPEED_AS_RIGHT"));
    return;
  }

  if (commandStartsWith(command, "PLATFORM_ALL_MOTORS_SPEED:")) {
    char *speedText = getTextAfterColon(command);
    int pwmValue = speedTextToPWM(speedText);
    platformLeftSpeed = pwmValue;
    platformRightSpeed = pwmValue;
    sendReply(F("OK PLATFORM_ALL_MOTORS_SPEED_AS_BOTH"));
    return;
  }

  sendReply(F("ERROR UNKNOWN_COMMAND"));
}

// =============================
// Serial Reading
// =============================

void readSerialLine(Stream &port, char *buffer, byte &index, const char *source) {
  while (port.available()) {
    char c = port.read();

    if (c == '\r') {
      continue;
    }

    if (c == '\n') {
      buffer[index] = '\0';
      handleCommand(buffer, source);
      index = 0;
      return;
    }

    if (index < 49) {
      buffer[index] = c;
      index++;
    } 
    else {
      buffer[index] = '\0';
      handleCommand(buffer, source);
      index = 0;
      return;
    }
  }
}

// =============================
// Setup
// =============================

void setup() {
  Serial.begin(9600);
  bluetooth.begin(9600);

  pinMode(PUMP_PIN, OUTPUT);
  digitalWrite(PUMP_PIN, PUMP_RELAY_OFF_LEVEL);

  pinMode(MOTOR_A_IN1, OUTPUT);
  pinMode(MOTOR_A_IN2, OUTPUT);
  pinMode(MOTOR_B_IN1, OUTPUT);
  pinMode(MOTOR_B_IN2, OUTPUT);
  pinMode(MOTOR_A_EN, OUTPUT);
  pinMode(MOTOR_B_EN, OUTPUT);

  // Force safe output states before the PCA9685 starts or any command is accepted.
  stopPlatform();
  digitalWrite(PUMP_PIN, PUMP_RELAY_OFF_LEVEL);

  Wire.begin();

  pwm.begin();
  pwm.setOscillatorFrequency(27000000);
  pwm.setPWMFreq(SERVO_FREQ);

  delay(1000);

  sendReply(F("READY ARM PLATFORM PNEUMATIC"));

  moveElbow(HOME_ELBOW_ANGLE);
  delay(300);

  moveWrist(HOME_WRIST_ANGLE);
  delay(300);

  moveGripper(HOME_GRIPPER_ANGLE);
  delay(300);

  pumpOff();
  stopPlatform();
}

// =============================
// Loop
// =============================

void loop() {
  servicePumpPulse();
  readSerialLine(Serial, usbBuffer, usbIndex, "USB");
  readSerialLine(bluetooth, btBuffer, btIndex, "Bluetooth");
}

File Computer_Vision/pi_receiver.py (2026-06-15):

import glob
import json
import queue
import socket
import threading
import time
from http.server import BaseHTTPRequestHandler, ThreadingHTTPServer

try:
    import serial
except ImportError:
    serial = None


# Edit these settings if the camera frame size or Arduino connection changes.
LISTEN_HOST = "0.0.0.0"
LISTEN_PORT = 5000
WEB_COMMAND_HOST = "0.0.0.0"
WEB_COMMAND_PORT = 5001
SERIAL_CANDIDATES = ["/dev/ttyACM0", "/dev/ttyUSB0"]
SERIAL_BAUD = 9600
FRAME_WIDTH = 320
CENTER_X = FRAME_WIDTH // 2
DEAD_ZONE = 20
BALL_TIMEOUT_SECONDS = 1.0
SERIAL_RETRY_SECONDS = 2.0
AUTONOMOUS_TRACKING_ENABLED = True
TARGET_DISTANCE_CM = 25.0
DISTANCE_DEAD_ZONE_CM = 4.0
PLATFORM_TRACKING_SPEED = "SLOW"
PICKUP_SEQUENCE_ENABLED = False
PICKUP_TRIGGER_DISTANCE_CM = 25.0
PICKUP_STABLE_DETECTIONS = 5
PICKUP_COOLDOWN_SECONDS = 8.0
PICKUP_ELBOW_ANGLE = 80
PICKUP_WRIST_ANGLE = 180
PICKUP_GRIPPER_ANGLE = 0
PICKUP_USE_SUCTION = False
WEB_COMMAND_PREFIXES = (
    "ELBOW_JOINT:",
    "WRIST_JOINT:",
    "NORMAL_GRIPPER_ANGLE:",
    "PLATFORM_LEFT_MOTOR_SPEED:",
    "PLATFORM_RIGHT_MOTOR_SPEED:",
    "PLATFORM_BOTH_MOTORS_SPEED:",
    "GRIPPING_TOOL:",
)
WEB_COMMAND_NAMES = {
    "HOME",
    "EMERGENCY_STOP",
    "RESET_EMERGENCY",
    "START_AUTO",
    "PAUSE",
    "RESUME",
    "STOP_AUTO",
    "SUCTION_CUP_ON",
    "SUCTION_CUP_OFF",
    "SUCTION_CUP_PULSE",
    "PLATFORM_LEFT",
    "PLATFORM_RIGHT",
    "PLATFORM_STOP",
    "PLATFORM_FORWARD",
    "PLATFORM_BACKWARD",
    "PLATFORM_FORWARD_RIGHT",
    "PLATFORM_FORWARD_LEFT",
    "PLATFORM_BACKWARD_RIGHT",
    "PLATFORM_BACKWARD_LEFT",
    "PLATFORM_MOTOR_TEST",
}
AUTONOMOUS_CONTROL_COMMANDS = {"START_AUTO", "PAUSE", "RESUME", "STOP_AUTO"}
WEB_COMMAND_QUEUE = queue.Queue()
BRIDGE_STATUS = {
    "arduino_connected": False,
    "serial_port": None,
    "last_serial_error": "not connected yet",
}


def is_web_command_allowed(command):
    if command in WEB_COMMAND_NAMES:
        return True
    return any(command.startswith(prefix) for prefix in WEB_COMMAND_PREFIXES)


class WebCommandHandler(BaseHTTPRequestHandler):
    def _send_json(self, status_code, payload):
        body = json.dumps(payload).encode("utf-8")
        self.send_response(status_code)
        self.send_header("Access-Control-Allow-Origin", "*")
        self.send_header("Access-Control-Allow-Methods", "GET, POST, OPTIONS")
        self.send_header("Access-Control-Allow-Headers", "Content-Type")
        self.send_header("Content-Type", "application/json")
        self.send_header("Content-Length", str(len(body)))
        self.end_headers()
        self.wfile.write(body)

    def do_OPTIONS(self):
        self._send_json(200, {"ok": True})

    def do_GET(self):
        if self.path != "/status":
            self._send_json(404, {"ok": False, "error": "unknown endpoint"})
            return

        self._send_json(
            200,
            {
                "ok": True,
                "queued_commands": WEB_COMMAND_QUEUE.qsize(),
                "arduino_connected": BRIDGE_STATUS["arduino_connected"],
                "serial_port": BRIDGE_STATUS["serial_port"],
                "last_serial_error": BRIDGE_STATUS["last_serial_error"],
            },
        )

    def do_POST(self):
        if self.path != "/command":
            self._send_json(404, {"ok": False, "error": "unknown endpoint"})
            return

        try:
            length = int(self.headers.get("Content-Length", "0"))
            raw_body = self.rfile.read(length).decode("utf-8")
            payload = json.loads(raw_body) if raw_body else {}
            command = str(payload.get("command", "")).strip()
        except Exception as error:
            self._send_json(400, {"ok": False, "error": f"bad request: {error}"})
            return

        if not is_web_command_allowed(command):
            self._send_json(400, {"ok": False, "error": "command not allowed"})
            return

        WEB_COMMAND_QUEUE.put(command)
        print(f"Website queued command: {command}")
        self._send_json(202, {"ok": True, "command": command})

    def log_message(self, format_string, *args):
        # Keep robot logs focused on accepted/rejected commands.
        return


def start_web_command_server():
    server = ThreadingHTTPServer((WEB_COMMAND_HOST, WEB_COMMAND_PORT), WebCommandHandler)
    thread = threading.Thread(target=server.serve_forever, daemon=True)
    thread.start()
    print(f"Website command bridge listening on {WEB_COMMAND_HOST}:{WEB_COMMAND_PORT}")
    return server


def find_serial_port():
    ports = []
    for candidate in SERIAL_CANDIDATES:
        ports.extend(glob.glob(candidate))
    ports.extend(glob.glob("/dev/ttyACM*"))
    ports.extend(glob.glob("/dev/ttyUSB*"))
    return next(iter(dict.fromkeys(ports)), None)


def open_arduino_serial():
    if serial is None:
        message = "pyserial is not installed. Install with: python3 -m pip install pyserial"
        BRIDGE_STATUS.update({"arduino_connected": False, "serial_port": None, "last_serial_error": message})
        print(message)
        return None

    port = find_serial_port()
    if not port:
        message = "Arduino serial port not found. Robot will stay stopped until serial is available."
        BRIDGE_STATUS.update({"arduino_connected": False, "serial_port": None, "last_serial_error": message})
        print(message)
        return None

    try:
        arduino = serial.Serial(port, SERIAL_BAUD, timeout=1)
        time.sleep(2)
        BRIDGE_STATUS.update({"arduino_connected": True, "serial_port": port, "last_serial_error": ""})
        print(f"Connected to Arduino on {port} at {SERIAL_BAUD} baud")
        return arduino
    except serial.SerialException as error:
        message = f"Could not open Arduino serial port {port}: {error}"
        BRIDGE_STATUS.update({"arduino_connected": False, "serial_port": port, "last_serial_error": message})
        print(message)
        return None


def write_arduino_command(arduino, command):
    if arduino is None or not arduino.is_open:
        return arduino, False

    try:
        arduino.write(f"{command}\n".encode("utf-8"))
        arduino.flush()
        print(f"Arduino <- {command}")
        return arduino, True
    except Exception as error:
        print(f"Serial write failed while sending {command}: {error}")
        try:
            arduino.close()
        except Exception:
            pass
        BRIDGE_STATUS.update(
            {
                "arduino_connected": False,
                "serial_port": BRIDGE_STATUS["serial_port"],
                "last_serial_error": f"Serial write failed: {error}",
            }
        )
        return None, False


def send_platform_command(arduino, command, last_command):
    if command == last_command:
        return arduino, last_command

    arduino, did_send = write_arduino_command(arduino, command)
    return arduino, command if did_send else last_command
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

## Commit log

2026-06-15 Add weeks 5-12 progress, computer vision, Arduino, and website
    - Progress reports: W5-W12 slides and PDFs added to Files/
    - Computer_Vision/: laptop_yolo_sender.py, pi_receiver.py, arm_calibration.py, dataset.yaml
    - Computer_Vision/Training_Results/train27/: YOLOv8 training metrics and weights (best.pt)
    - Arduino/: 2_motors_arduino_noross.ino sketch
    - Dataset/labels/: annotated YOLO training labels
    - Website/arm-controller/: interactive pick-and-place web UI (node_modules excluded)
    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
    [results.csv]
2026-06-15 Expand index.md with visuals, robot description, and new sections
    Added The Robot section with assembled arm and platform photos. Added CAD Design section with SolidWorks renders and torque simulation. Added Gripper Design section with gripper_design.jpg. Added Kin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
2026-06-15 Overhaul index.md with report content, GIFs, and full visual redesign
    - Problem statement rewritten from final report with design criteria table (CR-1 to CR-7)
    - Added impact statement and lessons learned from report
    - Team member table with roles from report section 3.1
    - Real workspace envelope dimensions (22 cm / 26 cm reach) from mechanical section
    - Gripper design updated: rack-and-pinion detail and dual-mode table from report
    - IK section: actual 100% workspace validation table (40/40 points) from MoveIt2 scan
    - Electrical section: full power budget table with real numbers (44.7 W peak, ~4 hr runtime)
    - Component selection results table (Arduino 4.20, C270 4.85, RPi4 4.60, MG995 4.30)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
2026-06-15 Add full ROS package with URDF, meshes, and launch files
    - ROS/urdf/ros.urdf: complete URDF kinematic model
    - ROS/meshes/: STL meshes for all 6 arm links
    - ROS/launch/display.launch: RViz visualisation
    - ROS/launch/gazebo.launch: Gazebo simulation
    - ROS/config/joint_names_ros.yaml: joint configuration
    - ROS/package.xml and CMakeLists.txt: ROS package manifest
    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
    [arm_link.STL, base_link.STL, elbow_link.STL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]
2026-06-15 Add distance estimation section, full report PDF, and expanded lessons learned
    - New Distance Estimation section with ball_distance.png and compass_distance.png
    - Focal calibration formula and per-object dimension explanation from report section 5.3
    - STABLE tracking description and distance reliability note
    - Final_Report_Group1.pdf added to Files/ and linked in Appendix
    - Lessons Learned expanded from 6 rows to full 8-point Version 2.0 section from report
    - Appendix split into Final Report and Progress Reports subsections
